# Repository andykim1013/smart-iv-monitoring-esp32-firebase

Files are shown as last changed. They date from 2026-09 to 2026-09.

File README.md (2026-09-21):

# Smart IV Monitoring System

**ESP32 · Firebase · Android · WPF 기반 디지털 수액 모니터링 시스템**

---

## 이 프로젝트는 무엇인가

- 2024년 대학교 학기설계(설계 및 프로젝트 기본II) 과목의 **팀 프로젝트**를 바탕으로 정리한 포트폴리오 저장소입니다.
- **교육 및 연구 목적의 프로토타입**이며, 실제 임상 현장에서 검증된 의료기기가 **아닙니다.**
- **실제 환자 모니터링이나 의료적 판단 목적으로 사용해서는 안 됩니다.**
- 이 저장소의 코드 중 일부는 2024년 당시 실제 소스이고, 일부는 2026년에 원본이 유실된 부분을 문서 근거로 재구성/재구현한 것입니다. 아래 "구현 상태" 표에서 정확히 구분하고 있으니 반드시 확인하십시오.

## 프로젝트 목적

당시 최종보고서를 근거로, 이 프로젝트는 다음을 목표로 했습니다.
- 로드셀(무게 센서)로 수액 팩의 무게 변화를 측정
- 적외선 센서로 수액 챔버 내 물방울 낙하를 감지
- 위 두 값으로 투여 속도와 잔여 시간을 추정
- Firebase Realtime Database로 측정값을 실시간 전송
- Android 앱과 WPF 데스크톱 프로그램으로 간호사가 원격에서 여러 환자의 수액 상태를 한눈에 모니터링

실제 구현을 넘어서는 효과(예: 임상적 안전성 향상, 의료사고 예방 등)를 이 저장소는 주장하지 않습니다. 그런 표현은 당시 보고서의 "기대효과" 서술일 뿐, 실측/임상시험으로 검증된 사실이 아닙니다.

## 시스템 구조

```
HX711 Load Cell ─┐
TCRT5000 (물방울 감지) ─┼→ ESP32 ──(WiFi)──→ Firebase Realtime Database
LCD (16x2 I2C) ───┘                                   │
                                                       ├──(읽기)──→ Android App
                                                       └──(읽기)──→ WPF Desktop App
```

- ESP32만 Firebase에 **값을 씁니다**(무게/시간/속도 측정 결과).
- Android, WPF는 모두 Firebase 값을 **읽기만** 합니다.
- 자세한 경로(path)와 근거는 [docs/firebase-setup.md](docs/firebase-setup.md) 참조.

## 구현 상태 (반드시 확인)

| 구성요소 | 현재 Repository 상태 | 출처 | 검증 |
|---|---|---|---|
| **ESP32 Firmware** | [실제 2024 원본] 그대로 보존 | `4조_디지털 수액 모니터링 시스템 개발/` 폴더의 `.ino` 원본 | 하드웨어 compile/run은 별도 미검증(소스 보존만 확인) |
| **Android — recovered-source** | [문서 원문 복원] 2024년 문서(최종보고서)에 실제 텍스트로 남아있던 코드를 그대로 옮김 | 최종보고서 ver1.5.0 부록 | 원문과 문자 단위 대조 완료 |
| **Android — reconstructed-app** | [신규 재구성] 2026년 공개 아카이브 정리 과정에서 Gradle/Manifest/리소스를 새로 작성 | recovered-source + 문서의 화면 설명 | `assembleDebug` **BUILD SUCCESSFUL**(컴파일/빌드만 검증, Firebase 런타임 연결은 별도 미검증) |
| **WPF** | [신규 재구현] 당시 전체 소스는 유실, 확인된 클래스/메서드/화면 명세만 근거로 새로 작성 | `desktop-app/README.md`의 기능 명세 | 정적 구조 검증만 완료, **실제 build 미검증**(.NET SDK 없음) |
| **CAD (.3dm/.stl)** | [실제 2024 원본] 파일명만 일반화, 내용은 SHA256 해시로 원본과 동일 확인 | 원본 폴더의 3D 케이스 설계 파일 | 해시 동일성 확인, `.3dm` 내부 문서 속성은 수동 확인 권장(아래 "알려진 한계" 참조) |

포트폴리오를 보시는 분이 **신규 재구현 코드를 2024년 원본으로 오해하지 않도록**, 이 표의 분류를 항상 기준으로 삼아주십시오.

## 실제 구현된 기능

- HX711 로드셀 기반 무게 측정
- TCRT5000 적외선 센서 기반 물방울 낙하 감지
- LCD(16x2, I2C) 출력
- NTP 서버를 이용한 시간 동기화
- 물방울 수/무게 변화 기반 투여 속도·잔여 시간·예상 종료시간 계산
- Firebase Realtime Database로 측정값 전송
- Android 앱의 층별 화면 이동 및 실시간 시작/종료 시간 표시(Firebase 리스너)
- WPF DataGrid 기반 환자 목록 모니터링(호실/이름/시작시간/종료시간/예상종료시간/진행도), 5초 주기 갱신, 환자정보 입력창

## 미구현 / 계획 (문서에만 존재)

다음은 팀 내부 메모(수정 계획)에 아이디어로만 있었고, 코드/회로 근거가 없어 이 저장소에 구현되어 있지 않습니다.
- 팔을 높게 들었을 때의 방지 알람 시스템
- 혈액 역류 방지 시스템

## 개발 과정 (초기 설계 → 최종 구현)

```
초기: Arduino UNO + Bluetooth + App Inventor(블록코딩)
   ↓
중간: ESP8266 + MySQL(구상)
   ↓
중간: ESP8266 + Firebase  ("아두이노에서 MySQL 직접 진입 불가" 판단에 따른 교체)
   ↓
최종: ESP32 + WiFi + Firebase Realtime Database + Android Studio + WPF
```

초기/중간 단계의 구성 요소(Arduino UNO, ESP8266, Bluetooth, MySQL, App Inventor)는 **모두 폐기된 설계이며 이 저장소의 최종 기술 스택에 포함되어 있지 않습니다.** 자세한 내용은 [docs/development-history.md](docs/development-history.md) 참조.

## Repository 구조

```
smart-iv-monitoring-esp32-firebase/
├── firmware/esp32_iv_monitor/          # [실제 원본] ESP32 펌웨어
├── mobile-app/
│   ├── recovered-source/               # [문서 원문 복원] Java 2개 클래스
│   └── reconstructed-app/              # [신규 재구성] 전체 Gradle 프로젝트 (빌드 성공)
├── desktop-app/
│   ├── README.md                       # WPF 기능 명세(2024년 문서 근거)
│   └── reimplemented-wpf/              # [신규 재구현] WPF 프로젝트 (build 미검증)
├── hardware/case-design/               # [실제 원본] 3D 케이스 설계(.3dm/.stl)
├── firebase/sample-data.json           # [신규 공개용 예시 데이터] synthetic
└── docs/                                # 복원/재구성 근거 문서 일체
```

## Android

- `mobile-app/recovered-source/`: **2024년 문서에서 복원**한 `MainActivity.java`, `MainActivity01.java`. 최종보고서에 package~닫는 중괄호까지 완결된 형태로 실려 있던 코드를 그대로 옮겼습니다(변수명/스타일 미수정, 원문의 버그·중복 import도 그대로 보존).
- `mobile-app/reconstructed-app/`: **2026년 공개 아카이브 정리 과정에서 재구성**한 Gradle 프로젝트 전체(Manifest, 리소스 XML, 빌드 설정)입니다. 당시 원본이 아닙니다.
- `gradle assembleDebug`가 **BUILD SUCCESSFUL**로 완료되어 `app-debug.apk`가 정상 산출되는 것을 확인했습니다. 이는 **소스/빌드 설정이 구조적으로 유효하다는 것**을 의미할 뿐이며, **Firebase 실시간 연결이 성공했다는 뜻이 아닙니다**(초기화 코드 관련 한계는 [docs/firebase-setup.md](docs/firebase-setup.md) 참조).

## WPF

- **2024년 당시 실제 WPF 전체 소스는 현재 자료에 남아있지 않습니다**(코드 본문은 스크린샷으로만 존재).
- `desktop-app/reimplemented-wpf/`는 최종보고서에서 확인된 클래스명(`MainWindow`, `Window2`), 메서드명, DataGrid 컬럼, Firebase 경로, 화면 흐름만 근거로 **공개용 포트폴리오 목적의 신규 재구현**입니다.
- Target Framework는 **net7.0-windows**를 사용했으며, 이는 2026년 공개용 재구현을 위해 선택한 값입니다. **2024년 당시 원본 WPF 프로젝트의 Target Framework는 문서에 근거가 없어 확인되지 않았습니다.**
- 이 PC에 .NET SDK가 없어 **실제 build는 미검증**입니다(XAML/구문 정적검증만 완료).
- Firebase 연동에 사용한 **FireSharp 패키지의 최신 .NET(net7.0-windows)과의 호환성도 미검증** 상태입니다.

## Firebase

- 이 저장소에는 **2024년 당시 실제 Firebase 자격증명(프로젝트 ID, API Key, 이메일/비밀번호, DB Secret)이 전혀 포함되어 있지 않습니다.**
- 이 저장소를 재현하려면 **본인의 Firebase 프로젝트(Realtime Database)를 별도로 준비**해야 합니다.
- 확인된 RTDB 경로는 `/802/StartWeight`, `/802/StartTime`, `/802/EndTime`, `/802/speed` 4개뿐입니다.
- ESP32/Android/WPF 각각의 설정 방법, 초기화 관련 한계, sample data는 [docs/firebase-setup.md](docs/firebase-setup.md)에 상세히 정리했습니다.

## Hardware / CAD

- 보드: ESP32 (초기에는 Arduino UNO → ESP8266을 거쳐 최종 교체)
- 센서: HX711 + 5kg 로드셀, TCRT5000 적외선 반사 센서(2개 구성)
- 출력: 16x2 I2C LCD(PCF8574)
- `hardware/case-design/iv_monitor_case.3dm`, `iv_monitor_case.stl`: 실제 3D 프린팅 출력에 사용된 설계 원본이며, 파일명만 공개용으로 일반화했습니다(내용은 SHA256 해시로 원본과 동일함을 확인).
- `.3dm` 파일 내부의 Rhino "문서 속성"(작성자 등 메타데이터)은 전용 도구 없이 완전히 검증하지 못했습니다 — **공개 전 Rhino에서 직접 열어 수동으로 확인하는 것을 권장합니다(manual review recommended).**

## Build / 검증 상태

| 컴포넌트 | 상태 |
|---|---|
| ESP32 Firmware | 원본 소스 보존. 실제 하드웨어 컴파일/실행은 이번 문서화 단계에서 별도로 검증하지 않았습니다. |
| Android reconstructed-app | `assembleDebug` 성공. Firebase 런타임 연결은 별도 미검증. |
| WPF reimplementation | 정적 구조(XAML well-formed, C# 구문) 검증 완료. .NET SDK 부재로 실제 build 미검증. |

## 보안 / 개인정보

- 실제 WiFi 자격증명 없음 (원본부터 자리표시자만 존재)
- 실제 Firebase 자격증명 없음
- 실제 환자 데이터 없음, 실제 의료정보 없음
- 팀원 개인정보(실명, 학번, 전화번호 등) 제거됨
- `firebase/sample-data.json`은 **신규 공개용 합성 예시 데이터**이며 실제 데이터가 아닙니다.

## 알려진 한계

- Android 코드 중 리소스(XML)·Manifest·Gradle 설정은 문서 기반으로 재구성한 것이며 당시 원본이 아닙니다.
- WPF는 전체가 기능 명세 기반의 신규 재구현입니다.
- WPF의 실제 build는 미검증입니다.
- FireSharp 패키지의 최신 .NET과의 호환성이 미검증입니다.
- 실제 Firebase 런타임 연결은 Android/WPF 모두 검증되지 않았습니다(Android는 초기화 코드 자체가 원본에 없었음).
- 실제 임상 검증이나 의료기기 인증을 받은 적이 없습니다.
- `.3dm` 파일 내부 메타데이터(작성자 등)는 일부 수동 확인이 필요할 수 있습니다.

## 원본 자료를 공개하지 않은 이유

원본 폴더에는 HWP/HWPX 최종보고서, PPTX 발표자료, 수업 평가표, 회의록 등이 있었지만 이 저장소에는 포함하지 않았습니다. 이유는 다음과 같습니다.
- 팀원 개인정보(실명, 학번, 연락처)가 포함되어 있음
- 일부 자료(평가표)에는 우리 팀 외 다른 학생들의 개인정보도 포함되어 있음
- 여러 버전이 중복되어 있어 공개 저장소에 그대로 둘 필요가 없음
- 수업 제출용 문서로, 공개 배포를 전제로 작성되지 않음

또한 원본 문서 중 일부에는 3D 모델링 소프트웨어의 비정상적인 설치 방법에 관한 설명이 포함되어 있었는데, 이 내용은 공개본에서 완전히 제외했습니다(구체적인 방법은 이 저장소 어디에도 기재하지 않았습니다).

## 관련 문서

- [docs/source-map.md](docs/source-map.md) — 모든 공개 파일의 출처와 근거 수준
- [docs/reconstruction-status.md](docs/reconstruction-status.md) — 컴포넌트별 복원/재구성 상태
- [docs/reconstruction-changes.md](docs/reconstruction-changes.md) — 3단계에서 이루어진 모든 변경의 상세 기록
- [docs/missing-source.md](docs/missing-source.md) — 여전히 원본이 없는 파일 목록과 근거
- [docs/development-history.md](docs/development-history.md) — 아키텍처 변천사(폐기 설계 포함)
- [docs/firebase-setup.md](docs/firebase-setup.md) — Firebase 연동 구조와 설정 방법

## 라이선스

이 저장소는 팀 프로젝트 결과물과 신규 재구성/재구현 코드가 혼재되어 있어, 라이선스는 아직 지정되지 않았습니다.

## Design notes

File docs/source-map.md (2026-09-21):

# Source Map

이 문서는 `smart-iv-monitoring-esp32-firebase/` 안의 각 공개용 파일이 원본 자료의 어디에서, 어떤 근거 수준으로 왔는지 추적합니다.

## Source of Truth 우선순위 (고정)
```
1순위: 실제 원본 소스파일 (.ino 등)
2순위: 최종보고서 ver1.5.0
3순위: 해당 기능 담당자의 개인보고서
4순위: 최종발표 V1.0.0
5순위: 구버전 보고서/발표자료
```
※ 상위 우선순위 자료가 있으면 그것을 그대로 사용하고, 여러 자료의 내용이 서로 다를 경우 "최신이니까"라는 이유만으로 임의로 합치지 않고 차이를 그대로 기록합니다.

## 파일별 매핑

| 공개용 파일 | 원본 출처 | 근거 수준 | 상태 | 비고 |
|---|---|---|---|---|
| `firmware/esp32_iv_monitor/esp32_iv_monitor.ino` | 원본 폴더 `4조_디지털 수액 모니터링 시스템 개발/` 내 하드웨어 담당 팀원의 `.ino` 파일 (1순위, 원본 파일명에 학번+실명 포함되어 이 문서에서는 생략) | 원본 파일 직접 복사 | **[실제 원본]** | SHA256 해시 일치, 파일명만 변경, 내용 100% 동일(검증 완료, 아래 참조) |
| `mobile-app/recovered-source/com/example/a02/MainActivity.java` | 최종보고서 ver1.5.0 부록#5 "어플리케이션 코드"(2순위), 본문 3-1 App 섹션과 문자 단위 동일, 원본 폴더 루트의 사용자메뉴얼 hwp(팀장 작성, 파일명에 학번+실명 포함되어 생략)에도 동일 텍스트 존재 | 문서 원문 텍스트 전체 발췌(package~닫는 중괄호까지 완결) | **[문서 원문 복원]** | 원문 그대로, 변수명/스타일 미수정. import 중복(`android.os.Bundle`, `androidx.appcompat.app.AppCompatActivity` 각 2회) 등 원문의 오탈자성 특징도 그대로 보존 |
| `mobile-app/recovered-source/com/example/a02/MainActivity01.java` | 최종보고서 ver1.5.0 부록#5(2순위), 본문 3-1 App 섹션과 문자 단위 동일(줄바꿈 차이만) | 문서 원문 텍스트 전체 발췌(package~닫는 중괄호까지 완결) | **[문서 원문 복원]** | 미사용 필드 `textView03`, `onCancelled`에서 `Starttime` 콜백인데 `textViewend1`을 갱신하는 원본 버그 등 그대로 보존 (임의 수정 없음) |
| `desktop-app/README.md` | 최종보고서 ver1.5.0 "3-2 프로그램"(2순위), WPF 담당 팀원 개인보고서(3순위) | 클래스/메서드명·역할 설명 텍스트만(코드 본문은 스크린샷이라 텍스트 없음) | **[설명만 존재]** | 실제 `.xaml`/`.cs` 코드는 어디에도 텍스트로 존재하지 않음. FireSharp 패키지명은 3순위 자료에서 텍스트로 직접 확인됨 |
| App Inventor 관련 자산 | 역설계 단계 회의록·PPT | 사용 사실만 텍스트로 확인, `.aia` 파일 없음 | **[폐기 설계]** | 최종 구현은 Android Studio로 전환되어 App Inventor 산출물은 최종 구현에 포함하지 않음 |
| Arduino UNO / ESP8266 / Bluetooth / MySQL 직접연동 | 1~3차 회의록 | 텍스트로 명시적 확인 | **[폐기 설계]** | 최종 아키텍처(ESP32+WiFi+Firebase)로 대체되어 반영하지 않음 |
| 팔 높게 들기 방지 알람 / 혈액 역류 방지 시스템 | `수정목록.txt` | 아이디어 수준 텍스트만 | **[미구현]** | 코드/회로 근거 전혀 없음 |

### 3단계 신규 추가분

| 공개용 파일 | 원본 출처 | 근거 수준 | 상태 | 비고 |
|---|---|---|---|---|
| `mobile-app/reconstructed-app/app/src/main/java/com/example/a02/MainActivity.java`, `MainActivity01.java` | recovered-source 동일 파일 | recovered-source 복사 + 컴파일 에러 1건 최소 수정(EdgeToEdge import 제거) | **[문서 원문 복원 + 최소 빌드 수정]** | 수정 내역은 `docs/reconstruction-changes.md` "Android 원문 수정 내역" 참조. recovered-source 자체는 무수정 |
| `mobile-app/reconstructed-app/app/src/main/res/layout/activity_main.xml`, `activity_main01.xml` | 최종보고서 ver1.5.0 "코드 설명" 텍스트(색상 hex, 텍스트 문구) + recovered Java의 View ID | 텍스트 근거 기반 근사 재현 (ConstraintLayout/CardView → 표준 위젯으로 대체, 사유는 reconstruction-changes.md) | **[신규 재구성]** | 원본 XML 아님. `card_background_main`(#ECF1E6), `room_background`(#EAF1E1)만 문서 원문 hex, 나머지 색상은 근사치 |
| `mobile-app/reconstructed-app/app/src/main/AndroidManifest.xml`, `*.gradle`, `colors.xml`, `strings.xml`, `themes.xml`, `border_shape.xml`, `card_background.xml` | 근거 없음(Manifest/Gradle), 또는 텍스트 근거 기반 근사(리소스) | 신규 작성 | **[신규 재구성]** | `docs/reconstruction-changes.md` 참조 |
| `desktop-app/reimplemented-wpf/**` (전체: .sln, .csproj, App/MainWindow/Window2 .xaml/.cs, PatientRow.cs, FirebaseSettings.example.cs) | `desktop-app/README.md`의 확인된 클래스/메서드/Firebase 경로/DataGrid 컬럼 명세 | 명세 기반 신규 구현(코드 본문 원문 없음) | **[신규 재구현]** | 당시 원본 WPF 소스가 아님. FireSharp 호환성 미검증(SDK 없음), 자세한 내용은 `docs/reconstruction-changes.md` |
| `hardware/case-design/iv_monitor_case.3dm`, `iv_monitor_case.stl` | 원본 `케이스 외형 출력 디자인.3dm`(2024-11-18) / `.stl`(2024-11-19) | 원본 파일 직접 복사 | **[실제 원본]** | SHA256 해시 일치, 파일명만 일반화. 선정 근거는 `docs/reconstruction-changes.md` "CAD 최종본 조사" 참조 |
| `케이스 외형 출력 디자인1.3dm` 등 나머지 CAD 후보 | 원본 폴더 | STL과 미대응 | **[판단 불가]**(공개용 미포함) | 최신 수정일이지만 대응 STL 없음 — 다음 단계에서 사용자 확인 후 포함 여부 결정 |

## ESP32 펌웨어 원본 동일성 검증 상세
```
원본: 2학년 2학기 설계/4조_디지털 수액 모니터링 시스템 개발/ 폴더 내 하드웨어 담당 팀원의 .ino 파일 (파일명에 학번+실명 포함되어 이 문서에서는 생략)
사본: firmware/esp32_iv_monitor/esp32_iv_monitor.ino

SHA256(원본) = 61faf2f7c8b4062545676607af73021d955608b7ad703fb4b8de788f67593ac7
SHA256(사본) = 61faf2f7c8b4062545676607af73021d955608b7ad703fb4b8de788f67593ac7
diff 결과   = 차이 없음 (0 lines)
파일 크기    = 13,711 bytes (동일)

결론: 파일명만 공개용으로 일반화되었을 뿐, 내용은 100% 동일한 원본입니다.
```

## 참고: 최종보고서 부록4(펌웨어 코드)와 .ino 원본의 관계
최종보고서 ver1.5.0 부록#4 "소스 코드"에 실린 ESP32 코드는 `.ino` 원본과 실질적으로 동일한 내용(변수/로직/주석 일치, 코드 종료부 문자열까지 정확히 일치 확인)입니다. 다만 이번 2단계에서는 **1순위 자료인 `.ino` 파일 자체**를 그대로 사용했으므로, 부록4 텍스트는 교차검증 용도로만 참고했습니다.

## Android 코드 본문·부록 간 동일성
최종보고서 본문(3-1 App 섹션)과 부록#5(어플리케이션 코드)에 실린 `MainActivity`/`MainActivity01` 코드는 줄바꿈 유무를 제외하면 **완전히 동일**합니다(문자 단위 diff 결과 실질 차이 없음). 서로 다른 버전이 아니라 같은 코드가 본문과 부록에 중복 수록된 것으로 판단했습니다.

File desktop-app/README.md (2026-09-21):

# Desktop App (WPF / C#) — 사양 문서 (소스 미확보)

> 이 문서는 **소스 코드가 아니라 복원 근거 문서**입니다.
> 원본 자료(최종보고서 ver1.5.0, WPF 담당자 개인보고서, 최종발표 V1.0.0)를 전수 조사한 결과,
> 이 프로그램의 **실제 텍스트 형태 전체 소스코드(.xaml, .xaml.cs, .csproj, .sln)는 현재 자료에 존재하지 않습니다.**
> 존재하는 것은 클래스/메서드 이름, 역할 설명, 화면 스크린샷(이미지)뿐이며, 이번 2단계에서는 이 정보만 문서화하고
> `.xaml` / `.xaml.cs` / `.csproj` / `.sln` 파일은 **생성하지 않았습니다.**

## 근거 자료
| 자료 | 근거 수준 |
|---|---|
| 최종보고서 ver1.5.0 "3-2 프로그램" 섹션 | 클래스/메서드 이름 + 역할 설명 텍스트, 코드 본문은 스크린샷(이미지) |
| WPF 담당 팀원 개인보고서 (원본 폴더 내 hwpx 파일 — 파일명에 학번+실명 포함되어 이 문서에서는 생략) | FireSharp 패키지 설치 절차 설명 + import 문 일부(`using FireSharp;` 등 패키지명만) 텍스트, 코드 본문은 스크린샷 |
| 최종발표 V1.0.0 PPT | 코드/클래스 관련 텍스트 없음 (해당 없음) |

## 확인된 기술 스택
- **UI 프레임워크**: WPF (Windows Presentation Foundation)
- **언어**: C#
- **Firebase 연동 패키지**: **FireSharp** (NuGet 패키지, WPF에서 Firebase Realtime Database 연동용으로 명시적으로 언급됨)
- **연동 대상**: Firebase Realtime Database (ESP32 펌웨어와 동일한 DB)

## 확인된 화면(클래스) 구성
### MainWindow
- 역할: 간호사 데스크가 여러 환자의 수액 상태를 한 화면에서 확인하는 메인 화면
- 구성 요소: `DataGrid` — 컬럼: **호실, 이름, 시작시간, 종료시간, 예상종료시간, 진행도**
- 동작: 프로그램 시작 시 호실을 제외한 셀은 공백으로 표시, 이름 열에 `Window2`를 여는 버튼 존재
- 실시간 업데이트: 타이머로 **5초 주기** 갱신, Firebase 값 변경 시에도 갱신

### Window2
- 역할: 환자 정보 입력 창 (이름, 투여 시간, 투여 용량, 수액 종류 입력)
- 동작: 입력 후 [확인] 버튼 클릭 시 창이 닫히고 `MainWindow`의 `DataGrid` 해당 행에 정보 반영
- 투여 시간은 분 단위 입력을 `TimeSpan`("00:00:00" 형식)으로 변환해 저장

## 확인된 메서드 이름과 역할 (본문 텍스트 근거, 구현 코드 본문은 없음)
| 메서드 | 소속(추정) | 역할 설명(원문 근거) |
|---|---|---|
| `UpdateInfo` | MainWindow | `Window2` 종료 시 실행, 입력값을 `DataGrid`에 반영 |
| `Info` | MainWindow | `MainWindow` 실행 시 `DataGrid` 행 생성 |
| `Setting` | MainWindow | Firebase에서 가져온 데이터를 가공 |
| `OnTimeEvent` | MainWindow | 행마다 데이터 존재 여부 확인 후 현재 값 계산·갱신 |
| `UpdateInfoForItem` | MainWindow | Firebase에서 가져온 데이터 변환 |
| `LoadData` | MainWindow | 프로그램 실행 시 `DataGrid` 생성(호실 제외 공백 처리) |
| `Read_Value` | MainWindow | Firebase에서 `speed`, `EndTime` 일부 데이터 조회 (`Window2` 종료 시 동작) |
| `BtnName_Click` | MainWindow | `[입력]` 버튼 클릭 시 `Window2` 실행 및 종료 후 값 저장 |
| `SetNowEnd` | MainWindow | 예상종료시간·진행도 계산에 필요한 시작무게/시작시간 저장, `DataGrid` 갱신 |
| `btn1_Click` | Window2 | 입력값 저장, `MainWindow`에서 사용 가능한 형식으로 변환 |

## 확인 가능한 Firebase 데이터 구조 (ESP32 펌웨어와 공유)
```
/802/StartTime
/802/EndTime
/802/speed
/802/StartWeight
```
(802는 예시 병실 호실 번호로, 문서 내 시연 예시입니다.)

## 환자정보 입력 흐름 (문서 근거)
```
프로그램 실행 → MainWindow 로드 → DataGrid에 호실만 표시(나머지 공백)
   ↓ [이름 열의 입력 버튼 클릭] (BtnName_Click)
Window2 표시 → 이름 / 투여시간(분→TimeSpan 변환) / 투여용량 / 수액종류 입력
   ↓ [확인] 버튼 (btn1_Click)
입력값 저장 → Window2 종료 → UpdateInfo 실행 → DataGrid 해당 행 갱신
   ↓ (백그라운드, 5초 주기)
Firebase에서 speed/EndTime 등 재조회(Read_Value) → 진행도·예상종료시간 재계산 → DataGrid 갱신
```

## 명시적으로 하지 않은 것 (2단계 기준)
- `.xaml` / `.xaml.cs` / `.csproj` / `.sln` 신규 작성 — 2단계에서는 하지 않음
- 위 메서드 이름을 기반으로 한 코드 본문 추측/작성 — 2단계에서는 하지 않음
- FireSharp 연동 코드, DataGrid 바인딩 코드 등 실제 구현부 재현 — 2단계에서는 하지 않음

## 3단계 갱신: 재구현 완료
위 명세를 근거로 3단계에서 [reimplemented-wpf/](reimplemented-wpf/)에 **[신규 재구현]** 코드를 작성했습니다(당시 원본이 아님). `.NET SDK`가 이 PC에 없어 실제 build는 검증하지 못했고(정적검증만 완료), FireSharp의 net7.0-windows 호환성도 미검증입니다. 상세 내용은 [../docs/reconstruction-changes.md](../docs/reconstruction-changes.md)와 [../docs/reconstruction-status.md](../docs/reconstruction-status.md)를 참조하십시오.

## 결론
WPF 데스크톱 프로그램은 **당시 실제 소스가 유실**된 상태였고, 이 문서는 재구현의 근거가 된 **기능 명세서**입니다. 실제 재구현 코드는 `reimplemented-wpf/`에 있습니다.

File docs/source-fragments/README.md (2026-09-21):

# Source Fragments

이 폴더는 "완전한 클래스가 아니어서 `.java`로 만들지 않은 부분 소스"를 기록하기 위한 폴더입니다.

## 현재 상태: 해당 없음 (Android)
최종보고서 ver1.5.0 + Android 담당 팀원 개인보고서를 전수 조사한 결과, 텍스트로 발견된 Android 코드는 **`MainActivity`, `MainActivity01` 2개뿐이며 둘 다 package~닫는 중괄호까지 완전한 클래스**였습니다. 그 외 활동(층별 병실 화면 등)에 대한 코드 텍스트는 전혀 발견되지 않았고(설명/스크린샷만 존재), "일부만 있는 코드 조각" 자체가 없어 이 폴더에는 현재 아무 파일도 없습니다. 완전한 두 클래스는 `mobile-app/recovered-source/`에 있습니다.

## WPF 관련 부분 증거
WPF(MainWindow/Window2)는 클래스명·메서드명·역할 설명 등 "부분 증거"가 있지만, 사용자 지시에 따라 이 폴더가 아니라 `../../desktop-app/README.md`에 기능 명세 형태로 정리했습니다(코드 조각이 아니라 스펙 문서이므로).

## 향후
다음 단계에서 하드웨어 담당 팀원 개인보고서 등을 더 정밀하게 재조사할 경우, 진짜 "일부만 있는 코드 조각"이 발견되면 이 폴더에 근거와 함께 `[부분 소스]`로 추가할 수 있습니다.

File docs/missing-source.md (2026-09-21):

# Missing Source

다음 단계(재구성)에서 다루어야 할, 현재 원본 텍스트가 없는 파일 목록입니다. 이번 2단계에서는 이 파일들을 **생성하지 않았습니다.**

> **3단계 갱신 안내**: 아래 목록 중 대부분은 3단계에서 `mobile-app/reconstructed-app/`, `desktop-app/reimplemented-wpf/`에 **[신규 재구성]/[신규 재구현]**으로 실제 작성되었습니다. 이 문서는 "당시 원본이 없었다"는 2단계 시점의 분석 기록을 그대로 보존하기 위해 수정하지 않았고, 각 항목이 어떤 파일로 재구성되었는지는 `docs/source-map.md`의 "3단계 신규 추가분" 표와 `docs/reconstruction-changes.md`를 참조하십시오. **유일하게 계속 미해결로 남은 항목은 "추가 Activity (2층~6층 병실 화면)"입니다** — 근거가 없어 3단계에서도 생성하지 않았습니다.

---

### AndroidManifest.xml
- 원본 존재 여부: 없음
- 근거: 최종보고서·개인보고서 어디에도 텍스트/설명 없음(존재 자체가 언급되지 않음)
- 복원 가능성: 불가(근거 없음)
- 신규 작성 필요 여부: 필요(재구성 단계에서 처음부터 작성해야 함, 이번 단계 범위 아님)

### Gradle 파일 (build.gradle, settings.gradle, gradle.properties, gradle wrapper)
- 원본 존재 여부: 없음
- 근거: 없음
- 복원 가능성: 불가
- 신규 작성 필요 여부: 필요(재구성 단계, 이번 단계 범위 아님)

### activity_main.xml
- 원본 존재 여부: 텍스트 원본 없음
- 근거: 최종보고서에 파일명("메인화면 레이아웃(activity_main.xml)")과 화면 스크린샷만 존재, `R.id.button2` 등 일부 리소스 ID는 `MainActivity.java` 코드에서 간접 확인 가능
- 화면/기능 설명: 층별 버튼 6개(1~6층), ConstraintLayout, CardView(층별 버튼 배경), TextView("건양대학병원", "4조"), ImageView(로고)
- 복원에 사용할 수 있는 자료: 최종보고서 스크린샷(이미지, 텍스트 아님), `MainActivity.java`가 참조하는 `R.id.button2`
- 신규 작성 필요 여부: 필요(레이아웃 XML 자체 재작성 필요, 이번 단계 범위 아님)

### activity_main01.xml
- 원본 존재 여부: 텍스트 원본 없음
- 근거: 최종보고서에 파일명("병실화면")과 화면 스크린샷만 존재. `R.id.textViewend1`, `R.id.textViewstart1`, `R.id.button05`는 `MainActivity01.java` 코드에서 간접 확인
- 화면/기능 설명: 801~803호실 등 TextView, 시작시간/종료시간/공실 여부 표시, 침대 번호 1~14, 사각 테두리(border_shape), 상단 건양대 로고+뒤로가기 버튼
- 복원에 사용할 수 있는 자료: 최종보고서 스크린샷(이미지), 코드 내 리소스 ID 참조
- 신규 작성 필요 여부: 필요(이번 단계 범위 아님)

### color.xml
- 원본 존재 여부: 텍스트 원본 없음
- 근거: "필요한 색상을 코드로 만들어 재사용" 설명 텍스트 + `@color/green`, `@color/green2` 참조가 `MainActivity`/설명 텍스트에서 확인됨(정확한 hex 값은 스크린샷에만 존재, 읽을 수 없음)
- 복원 가능성: 색상 이름만 확인, 실제 hex 값은 [내용 확인 불가]
- 신규 작성 필요 여부: 필요

### border_shape.xml
- 원본 존재 여부: 텍스트 원본 없음
- 근거: "병실 화면 호실마다 침대의 네모난 빈 틀을 만드는 코드" 설명 텍스트만 존재, 내용은 스크린샷
- 신규 작성 필요 여부: 필요

### 추가 Activity (2층~6층 병실 화면)
- 원본 존재 여부: 없음
- 근거: 최종보고서·개인보고서 모두 "802호실" 1개 사례만 텍스트/코드로 제시. "각 층의 호실을 한눈에 확인"이라는 목표 설명은 있으나, 층별로 별도 Activity가 몇 개 존재하는지, 이름 규칙(MainActivity02~06 등)이 무엇인지는 **어디에도 근거가 없음**
- 복원 가능성: 불가 — `MainActivity01`을 층/호실별로 복제했을 가능성은 있으나 추정일 뿐이므로 [내용 확인 불가]로 처리, 임의로 파일을 만들지 않음
- 신규 작성 필요 여부: 판단 보류(다음 단계에서 결정)

### WPF project files (.csproj, .sln)
- 원본 존재 여부: 없음
- 근거: 없음
- 신규 작성 필요 여부: 필요(재구현 단계, 이번 범위 아님)

### MainWindow.xaml / MainWindow.xaml.cs
- 원본 존재 여부: 텍스트 원본 없음(클래스명/메서드명/역할 설명만 텍스트, 코드 본문은 스크린샷)
- 근거: `desktop-app/README.md` 참조
- 복원 가능성: 불가(코드 본문 텍스트 없음)
- 신규 작성 필요 여부: 필요(재구현, 이번 범위 아님)

### Window2.xaml / Window2.xaml.cs
- 원본 존재 여부: 텍스트 원본 없음(위와 동일한 사유)
- 신규 작성 필요 여부: 필요(재구현, 이번 범위 아님)

### Firebase configuration (google-services.json, firebase config 등)
- 원본 존재 여부: 없음(원본 자료 어디에도 설정 파일 자체는 존재하지 않음, API Key/URL은 전부 플레이스홀더 텍스트로만 언급됨)
- 근거: `.ino` 및 최종보고서 부록의 `#define API_KEY "파이어베이스 API 키 작성"` 등
- 복원 가능성: 불가(실제 값 자체가 원본에도 없었음 — 유실이 아니라 "애초에 비공개 처리된 상태")
- 신규 작성 필요 여부: 다음 단계에서 사용자가 직접 발급해야 함(복원 대상 아님)

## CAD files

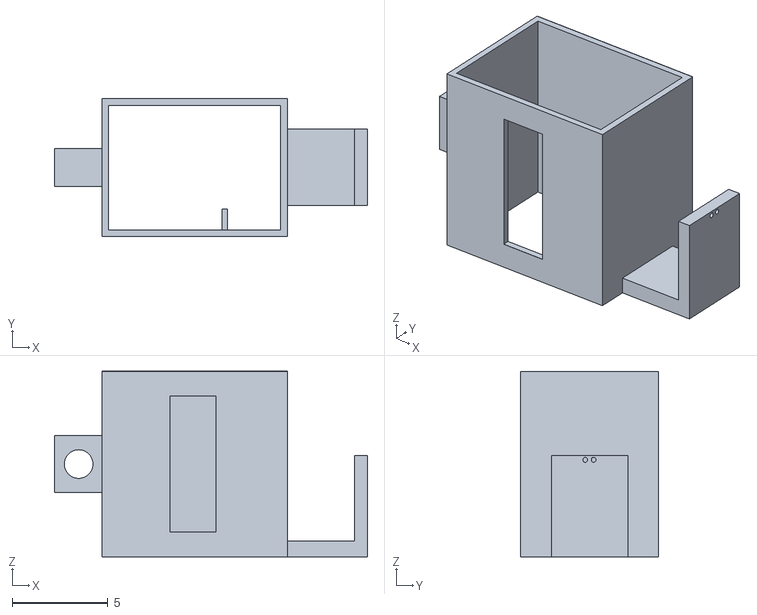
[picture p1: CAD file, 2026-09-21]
hardware/case-design/iv_monitor_case.stl
16.4 x 7.20 x 9.72

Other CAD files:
hardware/case-design/iv_monitor_case.3dm

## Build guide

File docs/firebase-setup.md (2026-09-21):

# Firebase Setup

이 문서는 이 저장소의 각 컴포넌트가 Firebase Realtime Database(RTDB)를 실제로 어떻게 사용하는지, 그리고 이 저장소를 직접 실행해보려는 사람이 무엇을 준비해야 하는지를 설명합니다. 아래 내용은 실제 코드(`firmware/`, `mobile-app/`, `desktop-app/`)를 다시 읽고 확인한 결과이며, 추측은 [확인 불가]로 표시했습니다.

## 1. Firebase Realtime Database의 역할

이 프로젝트에서 Firebase RTDB는 ESP32와 두 모니터링 클라이언트(Android, WPF) 사이의 유일한 데이터 통로입니다. 아두이노-앱-데이터베이스가 직접 연결되던 초기 구조(블루투스/MySQL, [docs/development-history.md](development-history.md) 참조)가 재설계 과정에서 이 구조로 바뀌었습니다.

```
ESP32 (HX711 + TCRT5000 + LCD)
   │  Firebase.setFloat / Firebase.setString  (쓰기)
   ▼
Firebase Realtime Database  ──────────────┐
   │  FirebaseDatabase.getInstance()...    │  IFirebaseClient.GetAsync(...)
   │  (읽기)                                │  (읽기)
   ▼                                        ▼
Android App (MainActivity01)         WPF Desktop (MainWindow)
```

ESP32만 쓰기(write)를 수행하고, Android와 WPF는 모두 읽기(read) 전용으로 동작합니다. 이는 recovered-source(Java)와 reimplemented-wpf(C#) 코드 어디에도 Firebase에 값을 **쓰는(set) 호출이 없다는 사실**로 확인했습니다.

## 2. 확인된 RTDB path / schema

세 컴포넌트(펌웨어, Android, WPF)의 실제 코드를 대조한 결과, 아래 4개 경로만 확인되었습니다. `802`는 최종보고서·코드 양쪽에서 예시로 등장하는 병실/침대 번호이며, 실제로는 임의의 호실 번호가 들어갈 수 있는 자리입니다.

| Path | 타입 | 쓰는 주체 | 읽는 주체 |
|---|---|---|---|
| `/802/StartWeight` | float | ESP32 | (읽는 코드 없음, 확인 안 됨) |
| `/802/StartTime` | string | ESP32 | Android |
| `/802/EndTime` | string | ESP32 | Android, WPF |
| `/802/speed` | float | ESP32 | WPF |

이 4개 외에 코드/문서로 확인되는 필드는 없습니다. 문서 본문에는 "환자 이름, 투여 용량, 수액 종류"도 언급되지만, 이 값들이 실제로 Firebase에 쓰였다는 코드 근거는 없어(WPF Window2 입력값은 화면에만 반영되는 것으로 확인) **schema에 포함하지 않았습니다.**

## 3. ESP32가 사용하는 설정

`firmware/esp32_iv_monitor/esp32_iv_monitor.ino`(2024년 실제 원본, 이번 4단계에서도 **수정하지 않음**)는 다음 상수를 코드에 직접 선언합니다.

```cpp
const char* ssid = "와이파이 이름 작성";
const char* password = "와이파이 비밀번호 작성";
#define API_KEY "파이어베이스 API 키 작성"
#define DATABASE_URL "파이어 베이스 URL 주소 작성"
#define USER_EMAIL "사용자 이메일"
#define USER_PASSWORD "비밀번호 작성"
```

원본부터 실제 값이 아니라 사람이 채워 넣어야 할 자리표시자였습니다. 이 저장소에서는 이 구조를 `secrets.h` 같은 별도 헤더 파일로 리팩터링하지 않았습니다 — **원본 소스를 그대로 보존하는 것이 우선**이기 때문입니다. 이 파일을 직접 사용하려면 위 6개 값을 본인의 WiFi/Firebase 정보로 직접 채워 넣으십시오(파일을 열어 편집).

## 4. Android가 사용하는 설정

`mobile-app/reconstructed-app/app/build.gradle`을 확인한 결과:
- `com.google.gms:google-services` 플러그인이 적용되어 있지 **않습니다.**
- `google-services.json`을 참조하는 코드/설정이 어디에도 없습니다.
- `recovered-source`/`reconstructed-app`의 `MainActivity.java`, `MainActivity01.java`에도 `FirebaseApp.initializeApp(...)`이나 `FirebaseOptions`를 이용한 수동 초기화 코드가 없습니다. `FirebaseDatabase.getInstance()`를 곧바로 호출할 뿐입니다.

**결론**: 현재 Gradle 구조는 `google-services.json`을 필요로 하지 않지만, 그 이유는 "설정이 필요 없어서"가 아니라 **Firebase 초기화 코드 자체가 원본 문서에 없어서**입니다. 즉 이 상태로는 앱을 실제 기기에서 실행해도 `FirebaseDatabase.getInstance()` 호출 시점에 "Default FirebaseApp이 초기화되지 않았다"는 런타임 오류가 발생할 가능성이 높습니다. 이는 **알려진 한계**이며, 이번 4단계(문서화 단계)에서는 코드를 추가로 개발하지 않았으므로 `google-services.example.json` 같은 템플릿도 만들지 않았습니다. 실제로 앱을 동작시키려면 다음 단계 중 하나가 **추가로 필요**합니다(둘 다 이번 저장소 범위 밖의 작업):
1. `com.google.gms:google-services` 플러그인 적용 + 본인의 `google-services.json` 추가, 또는
2. `Application` 클래스 등에서 `FirebaseOptions.Builder()`로 API Key/DB URL을 직접 넣어 수동 초기화하는 코드 추가

## 5. WPF가 사용하는 설정

`desktop-app/reimplemented-wpf/IvMonitorDesktop/FirebaseSettings.example.cs`에 두 필드만 존재합니다.

```csharp
public const string AuthSecret = "YOUR_FIREBASE_AUTH_SECRET";
public const string BasePath = "https://YOUR_PROJECT_ID.firebaseio.com/";
```

`MainWindow.xaml.cs`는 이 두 필드(`FirebaseSettings.AuthSecret`, `FirebaseSettings.BasePath`)만 참조하며 다른 필드는 없습니다. 실제로 사용하려면 `FirebaseSettings.example.cs`를 복사해 `FirebaseSettings.cs`(같은 폴더, 같은 네임스페이스)로 만들고 두 값을 채우십시오. `FirebaseSettings.cs`는 `.gitignore`에 등록되어 있어 실수로 커밋되지 않습니다.

## 6. Credential을 Repository에 포함하지 않는 정책

이 저장소에는 다음이 **전혀 포함되어 있지 않습니다.**
- 2024년 당시 실제 Firebase 프로젝트 ID
- 실제 Firebase API Key / DB URL
- 실제 Firebase 로그인 이메일/비밀번호 또는 Auth Secret
- 실제 WiFi SSID/비밀번호

이 저장소를 재현하려면 **사용자가 자신의 Firebase 프로젝트(Realtime Database 활성화)를 별도로 준비**해야 하며, 위 3~5절의 설정 자리에 자신의 값을 채워야 합니다.

## 7. Android build 성공 ≠ Firebase runtime 연결 검증

`mobile-app/reconstructed-app`는 `gradle assembleDebug`로 **컴파일/빌드 성공**을 확인했습니다(`docs/reconstruction-status.md` 참조). 이것은 **소스 코드 구조와 의존성 해석이 정상**임을 의미할 뿐이며, 실제 기기/에뮬레이터에서 앱을 실행해 Firebase에 실시간으로 연결되는지는 **검증하지 않았습니다**(4절에서 설명한 초기화 누락 문제도 있어 현재 상태로는 런타임 연결이 되지 않을 가능성이 높습니다).

## 8. WPF Firebase 연동은 build/runtime 모두 미검증

`desktop-app/reimplemented-wpf`는 이 PC에 .NET SDK가 설치되어 있지 않아 `dotnet build` 자체를 실행하지 못했습니다(XAML/구문 정적검증만 완료). 따라서 컴파일 성공 여부, FireSharp 패키지의 실제 호환성, Firebase 런타임 연결 모두 **미검증** 상태입니다.

## 9. Sample data

`firebase/sample-data.json`에 위 2절의 schema(경로 4개)만 사용한 **신규 공개용 예시 데이터**를 두었습니다. 실제 2024년 DB 덤프가 아니며, 실제 환자정보·의료정보를 포함하지 않습니다.

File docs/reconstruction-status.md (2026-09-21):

# Reconstruction Status

컴포넌트별 복원 상태를 기록합니다. "복원"은 근거가 명확한 것만 포함하며, 근거 없는 추측은 포함하지 않습니다.

---

## ESP32 Firmware
**상태: 실제 원본 확보 (100%)**
- `esp32_iv_monitor.ino` — 원본 파일 SHA256 해시 일치, 완전 동일 사본
- 센서 핀 설정, HX711 무게 처리, TCRT5000 물방울 카운트, LCD 출력, 시간 계산/예상 종료시간 계산, Firebase 데이터 경로, NTP, loop 주기 — **모두 원본 그대로이며 어떤 것도 리팩터링하지 않았습니다.**
- WiFi SSID/비밀번호, Firebase API Key/URL/이메일/비밀번호는 원본부터 "OOO 작성"류 플레이스홀더였고, 이번 단계에서는 `secrets.h` 구조로도 바꾸지 않았습니다(다음 공개 정리 단계에서 별도 판단).

## Android (mobile-app)
**상태(3단계 갱신): Original source partially recovered (2 classes) + reconstructed build scaffolding added — BUILD SUCCESSFUL**

- `recovered-source/`: 아래 "부분 소스 확보" 내용 그대로, **3단계에서 한 글자도 수정하지 않음**
- `reconstructed-app/`: recovered-source를 복사해 최소 수정(컴파일 에러 1건)한 뒤, Gradle/Manifest/리소스를 신규 재구성해 실제 `assembleDebug` 빌드에 **성공**(APK 산출 확인, 이후 `gradle clean`으로 빌드 산출물은 정리함)
- 상세 검증 내용은 이 문서 하단 "3단계: 실제 빌드 검증 결과" 참조

**상태(2단계): 부분 소스 확보 — 완전한 클래스 2개만 복원**
- 문서(최종보고서 ver1.5.0 본문+부록, 사용자메뉴얼)에서 다음 2개 클래스가 **package~닫는 중괄호까지 완결된 형태**로 확인되어 `.java`로 복원했습니다.
  - `MainActivity.java` — package, imports, class 선언, `onCreate`, 버튼 클릭 리스너, `Intent` 이동, 닫는 중괄호까지 전부 존재
  - `MainActivity01.java` — package, imports, class 선언, 필드(`textView03`, `textViewend1`, `textViewstart1`, `Starttime`, `Endtime`), `onCreate`, Firebase `ValueEventListener` 2개(`onDataChange`/`onCancelled`), 버튼 클릭 리스너, 닫는 중괄호까지 전부 존재
- **원문 그대로 보존한 특이사항(임의 수정하지 않음)**:
  - `MainActivity.java`: `import android.os.Bundle;`, `import androidx.appcompat.app.AppCompatActivity;`가 각각 2회 중복 선언됨(원본 그대로)
  - `MainActivity01.java`: 필드 `textView03`이 선언만 되고 본문에서 사용되지 않음(원본 그대로)
  - `MainActivity01.java`: `Starttime.addValueEventListener(...)`의 `onCancelled` 콜백 내부에서 `textViewstart1`이 아니라 `textViewend1.setText(...)`을 호출함 — **원본 문서에 실제로 이렇게 적혀 있는 버그로 보이는 부분**이며, 임의로 고치지 않고 그대로 옮겼습니다.
  - 두 클래스 모두 최종보고서 텍스트에는 코드 라인에 들여쓰기가 없는 상태로 남아 있었습니다(HWP 원본의 문단 서식 때문인지, 학생이 원래 들여쓰기 없이 작성했는지는 확인 불가). 이번 복원에서는 **원문 그대로 들여쓰기를 추가하지 않고** 발췌된 형태를 유지했습니다.
- **복원하지 않은 것**: 그 외 언급되는 XML 리소스, Manifest, Gradle 설정 — 텍스트 원문이 없어 `docs/missing-source.md`에 별도 기록

## WPF (desktop-app)
**상태(3단계 갱신): Original source unavailable — portfolio reimplementation added (build UNVERIFIED, no .NET SDK)**

- `desktop-app/README.md`(기능 명세)는 2단계 그대로 유지
- `reimplemented-wpf/`: README의 명세(클래스명 10개 메서드, DataGrid 6컬럼, Firebase 경로, 5초 주기, FireSharp)를 근거로 **전체 신규 재구현**(MainWindow, Window2, PatientRow, FirebaseSettings.example)
- **build는 검증하지 못했습니다**: 이 PC에 .NET SDK가 설치되어 있지 않아(`dotnet --list-sdks` 결과 없음, 런타임만 존재) `dotnet restore`/`build` 자체를 실행할 수 없었습니다. XAML well-formed 여부와 C# 중괄호/괄호 균형 등 **정적검증만 완료**했습니다.
- FireSharp(2.0.4)은 .NET Framework 4.5 세대 라이브러리로 알려져 있어 net7.0-windows와의 실제 호환성이 미검증 상태입니다(다른 라이브러리로 임의 교체하지 않음). 상세는 `docs/reconstruction-changes.md` 참조.

## CAD
**상태(3단계 갱신): 실제 원본 보존 + 공개용 최종본 1쌍 복사 완료(해시 검증됨)**
- 최종본으로 선정: `케이스 외형 출력 디자인.3dm`(2024-11-18, STL과 페어링됨) + `케이스 외형 출력 디자인.stl`(2024-11-19, 폴더 내 유일한 STL)
- `hardware/case-design/iv_monitor_case.3dm`, `iv_monitor_case.stl`로 파일명만 일반화해 복사, SHA256 해시로 원본과 완전 동일함을 확인
- `.3dmbak`(3개)와 "케이스 외형 출력 디자인1.3dm"(날짜상 더 최신이나 대응 STL 없음)은 복사하지 않음 — 근거는 `docs/reconstruction-changes.md` "CAD 최종본 조사" 참조
- 3dm 내부 OpenNURBS "문서 속성"(작성자 등)은 전용 도구 없이 완전히 확인 불가 — [확인 불가]로 명시, 텍스트 패턴 스캔으로는 PII 미검출

---

## 3단계: 실제 빌드 검증 결과

### Android
```
환경: Gradle 8.9(로컬 캐시), AGP 8.6.0, JDK 21, Android SDK platform 34/35 (모두 이 PC에 기존 설치되어 있던 것 사용, 신규 설치 없음)
명령: gradle assembleDebug
결과: BUILD SUCCESSFUL — app-debug.apk 산출 확인 후 gradle clean으로 산출물 정리
```
과정에서 발견/조치한 문제 2건(모두 `docs/reconstruction-changes.md`에 상세 기록):
1. `firebase-database`가 끌어오는 구버전 `kotlin-stdlib-jdk7/jdk8`이 최신 `kotlin-stdlib`과 클래스 중복 → 버전을 올리지 않고 구버전 transitive 모듈만 `exclude`
2. `androidx.constraintlayout`/`androidx.cardview`의 커스텀 XML 속성이 이 환경의 AAPT2 리소스 링크 단계에서 인식되지 않음(원인 미특정, 한글 경로·캐시 오염은 배제됨) → 표준 프레임워크 위젯(`LinearLayout`+shape drawable)으로 대체

### WPF
```
환경: .NET 7 런타임만 설치(SDK 없음)
결과: 정적검증(XAML well-formed, C# 중괄호/괄호 균형)만 완료 / 실제 build 미검증
```

## App Inventor
**상태: 최종 구현에서 제외**
- 역설계 단계(2024.09)에서 사용된 사실은 회의록/PPT로 확인되나, `.aia` 원본 파일이 자료에 없고 최종 구현은 Android Studio로 전면 교체됨
- 새 App Inventor 프로젝트를 생성하지 않았으며, 전환 과정만 `development-history.md`에 서술

## 폐기 아키텍처 (Arduino UNO / ESP8266 / Bluetooth / MySQL 직접연동)
**상태: 최종 구현에서 완전히 제외**
- 회의록(2·3차)에 폐기 결정이 명시적으로 기록되어 있어, 최종 구현물에 포함하지 않고 `development-history.md`에 "폐기 설계"로만 기록

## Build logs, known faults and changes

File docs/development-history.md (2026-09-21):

# Development History

회의록·발표자료에서 확인된 기술적 의사결정 변화만 정리했습니다(개인정보 제외). 최종 구현과 폐기안을 명확히 구분합니다.

## 아키텍처 변천사

```
[역설계 단계 (2024.09)]
Arduino UNO + Bluetooth 통신 + App Inventor(블록코딩) + MySQL(구상)
데이터 흐름: 아두이노 → 블루투스 통신 → 앱인벤터 → 데이터베이스
        │
        │  1차 회의(재설계 착수): ESP8266 채택, MySQL 유지
        ▼
[재설계 1차 (2024.10 초)]
ESP8266 + MySQL(구상) + 적외선 트래킹 센서
        │
        │  2차 회의: "아두이노에서 MySQL로 직접 진입 불가" 판단
        │  → 데이터베이스를 MySQL에서 Firebase로 교체
        ▼
[재설계 2차]
ESP8266 + Firebase
데이터 흐름: 아두이노 → 데이터베이스(Firebase) → 모니터링 프로그램
        │
        │  3차 회의: 광센서 각도 조정, 센서 2개 구성으로 회로 수정
        │  → 보드를 ESP8266에서 ESP32로 교체
        ▼
[최종 구현 (2024.12 완료)]
ESP32 + WiFi(내장) + Firebase Realtime Database
+ Android Studio 앱 (App Inventor 대체)
+ WPF(C#) 데스크톱 프로그램 (FireSharp로 Firebase 연동)
```

## 최종 구현에 포함된 것
- ESP32 보드, WiFi(내장 모듈), HX711 로드셀, TCRT5000 광센서(2개 구성), LCD(I2C)
- Firebase Realtime Database
- Android Studio 기반 모바일 앱 (Java)
- WPF(C#) 기반 데스크톱 모니터링 프로그램 (FireSharp)
- Rhino 8 기반 3D 프린팅 케이스

## 폐기된 설계 (최종 구현에 포함되지 않음)
| 폐기 항목 | 대체된 것 | 폐기 시점(근거) |
|---|---|---|
| Arduino UNO | ESP8266 → ESP32 | 재설계 착수 시점 |
| Bluetooth 통신 | WiFi(ESP32 내장) | 재설계 초기 |
| App Inventor(블록코딩) | Android Studio(Java) | 재설계 진행 중 |
| MySQL 직접연동 | Firebase Realtime Database | 2차 회의("아두이노에서 MySQL 직접 진입 불가") |
| ESP8266 | ESP32 | 3차 회의(회로 수정과 함께 교체) |

## 미구현/계획 수준 아이디어 (코드화하지 않음)
다음 항목은 `수정목록.txt`(팀 내부 메모)에 아이디어로만 존재하며, 회로도·코드·시연 근거가 전혀 없어 **[미구현/계획]**으로만 표시합니다.
- 팔 높게 들기 방지 알람 시스템
- 혈액 역류 방지 시스템

## App Inventor 처리 방침
초기 역설계 단계에서 실제로 사용된 사실은 확인되지만, `.aia` 프로젝트 파일 원본이 자료에 존재하지 않고 최종 시스템은 Android Studio로 완전히 대체되었습니다. 따라서 이번 복원 작업에서는:
- App Inventor용 파일을 새로 만들지 않았습니다.
- 최종 모바일 앱 코드(`mobile-app/`)에는 App Inventor 관련 산출물을 포함하지 않았습니다.
- 이 문서에만 전환 과정으로 기록합니다.

## 제외된 내용에 대한 안내
원본 최종보고서에는 3D 모델링 소프트웨어(Rhino 8)의 **비정상적인 설치 방법에 관한 설명**이 일부 포함되어 있었습니다. 해당 내용은 공개용 저장소 정책상 부적절하다고 판단하여 이 작업폴더의 어떤 문서에도 옮기지 않았습니다(구체적 방법·파일명·절차는 기록하지 않음).

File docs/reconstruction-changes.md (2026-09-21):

# Reconstruction Changes (3단계)

이 문서는 신규 코드와 과거 원본 코드를 절대 혼동하지 않도록, 3단계에서 이루어진 모든 변경/생성 작업을 6가지로 분리해 기록합니다.

---

## 1. 원본 그대로 복사
- `firmware/esp32_iv_monitor/esp32_iv_monitor.ino` — 2단계에서 이미 완료(변경 없음, SHA256 동일 유지)

## 2. 문서 원문 그대로 복원
- `mobile-app/recovered-source/com/example/a02/MainActivity.java`, `MainActivity01.java` — 2단계에서 이미 완료, **이번 3단계에서 한 글자도 수정하지 않았습니다.**

## 3. 신규 Android 재구성 (`mobile-app/reconstructed-app/`)
모두 **[신규 재구성]**이며 당시 원본이 아닙니다.

| 파일 | 근거 |
|---|---|
| `settings.gradle`, `build.gradle`, `gradle.properties`, `app/build.gradle` | 원본 Gradle 파일 없음. 이 PC의 기존 Android SDK(platform 34/35, build-tools 34.0.0/35.0.0)와 로컬 Gradle 캐시(AGP 8.6.0/8.7.2, Gradle 8.9)에 맞춰 새로 작성 |
| `app/src/main/AndroidManifest.xml` | 원본 없음. recovered-source의 실제 Activity 2개(MainActivity, MainActivity01)만 선언, INTERNET permission만 추가(Firebase 통신 근거) |
| `app/src/main/java/com/example/a02/MainActivity.java`, `MainActivity01.java` | recovered-source를 그대로 복사한 뒤, **컴파일 오류 1건만** 최소 수정(아래 "Android 원문 수정 내역" 참조) |
| `app/src/main/res/layout/activity_main.xml`, `activity_main01.xml` | 원본 XML 없음. 최종보고서 ver1.5.0 "코드 설명" 원문 텍스트(ConstraintLayout/CardView 속성값, 텍스트 문구, 색상 hex)를 근거로 재구성. recovered Java가 참조하는 View ID(`button2`, `textViewend1`, `textViewstart1`, `button05`)만 정확히 반영 |
| `app/src/main/res/values/colors.xml` | `#ECF1E6`, `#EAF1E1`은 문서 원문 hex 값 그대로. `green`/`green2`는 이름만 언급되고 실제 hex는 없어 **reconstructed approximation**으로 표시 |
| `app/src/main/res/values/strings.xml`, `themes.xml` | 신규 작성(Material3 미도입, AppCompat 최소 테마만 사용) |
| `app/src/main/res/drawable/border_shape.xml` | 원문 텍스트("네모난 빈 틀") 근거로 재구성, 색상/두께는 근사치 |
| `app/src/main/res/drawable/card_background.xml` | 아래 "빌드 호환 대체" 참조 |

### Android 원문 수정 내역 (recovered-source → reconstructed-app 사본, 이 사본에서만 적용)
| 파일 | 수정 내용 | 사유 |
|---|---|---|
| `MainActivity.java` | `import androidx.activity.EdgeToEdge;` 삭제 | 원문에서도 실제로 사용되지 않는 import였고, 빌드에 사용한 `androidx.activity:activity:1.7.0`에는 이 클래스가 없어 컴파일 에러(`cannot find symbol`) 발생. **명백한 compile error에 대한 최소 수정** |
| `MainActivity01.java` | 동일하게 `import androidx.activity.EdgeToEdge;` 삭제 | 위와 동일 사유 |

그 외 원문의 특이사항(중복 import, 미사용 필드 `textView03`, `onCancelled`에서 `textViewend1`을 잘못 갱신하는 부분)은 **빌드를 막지 않으므로 수정하지 않고 그대로 두었습니다.**

### 빌드 호환 대체 (라이브러리 → 표준 위젯)
최종보고서 원문은 메인화면에 `ConstraintLayout`+`CardView` 사용을 명시하고 있어 처음에는 `androidx.constraintlayout:constraintlayout:2.1.4`, `androidx.cardview:cardview:1.0.0`를 그대로 포함했습니다. 그러나 이 빌드 환경(Gradle 8.9 + AGP 8.6.0 + JDK 21)에서 두 라이브러리의 커스텀 XML 속성(`app:layout_constraintTop_toTopOf`, `app:cardCornerRadius` 등)이 `processDebugResources`(AAPT2 리소스 링크) 단계에서 **"attribute res-auto:... not found"** 오류로 전부 실패하는 것을 확인했습니다.

진단 과정(모두 재현됨):
1. 프로젝트 경로에 한글이 포함되어 발생하는 문제인지 의심 → ASCII 전용 임시 경로로 복사해 재현 → **동일하게 실패**(한글 경로 문제 아님)
2. Gradle 캐시가 오염된 것인지 의심 → `gradle clean --rerun-tasks`로 캐시 무효화 후 재시도 → **동일하게 실패**
3. ConstraintLayout/CardView가 실제로 `debugCompileClasspath`에 해석되는지 확인 → 정상 해석됨, `ExtractAarTransform`도 정상 수행됨(`--info` 로그로 확인)
4. CardView 없이 ConstraintLayout 속성만 단독으로 테스트 → **동일하게 실패**(두 라이브러리 각각의 문제가 아니라 공통적인 환경 이슈로 판단)
5. 표준 프레임워크 위젯(`LinearLayout`, `Button`, `TextView`)만으로 별도 레이아웃을 만들어 테스트 → **정상 링크 성공**

원인을 완전히 특정하지는 못했으나(이 환경의 AAPT2/AGP 조합에 한정된 문제로 추정), "단순하게 재현"이라는 3단계 원칙에 따라 **ConstraintLayout/CardView를 걷어내고 표준 LinearLayout + shape drawable(`card_background.xml`, 문서 원문의 `cardCornerRadius=20dp`, `cardBackgroundColor=#ECF1E6` 값을 그대로 반영)로 동일한 배치/색상을 재현**했습니다. `app/build.gradle`에서 두 의존성도 제거했습니다. 라이브러리를 임의로 "다른 라이브러리"로 바꾼 것이 아니라, 문서에 없는 라이브러리 자체를 걷어내고 프레임워크 기본 기능으로 대체한 것입니다.

## 4. 신규 WPF 재구현 (`desktop-app/reimplemented-wpf/`)
모두 **[신규 재구현]**이며 당시 원본이 아닙니다. `desktop-app/README.md`에 정리된 확인된 클래스명/메서드명/DataGrid 컬럼/Firebase 경로/5초 주기 갱신/환자정보 입력 흐름만 근거로 새로 작성했습니다.

| 파일 | 내용 |
|---|---|
| `IvMonitorDesktop.sln`, `IvMonitorDesktop.csproj` | 신규 작성. Target Framework는 "16. WPF Target Framework" 참조 |
| `App.xaml`, `App.xaml.cs` | 표준 WPF 진입점(최소) |
| `MainWindow.xaml`, `MainWindow.xaml.cs` | DataGrid 6컬럼(호실/이름/시작시간/종료시간/예상종료시간/진행도) + 확인된 메서드명(UpdateInfo, Info, Setting, OnTimeEvent, UpdateInfoForItem, LoadData, Read_Value, BtnName_Click, SetNowEnd) 전부 반영 |
| `Window2.xaml`, `Window2.xaml.cs` | 환자정보 입력창(이름/투여시간(분→TimeSpan)/투여용량/수액종류) + `btn1_Click` |
| `PatientRow.cs` | DataGrid 바인딩용 모델(원문에 클래스명 언급 없음, 신규 설계) |
| `FirebaseSettings.example.cs` | config example/template. 실제 AuthSecret/BasePath 없음 |

## 5. CAD 선별/파일명 변경
- 최종본으로 선정: `케이스 외형 출력 디자인.3dm`(2024-11-18) + `케이스 외형 출력 디자인.stl`(2024-11-19) → 이 둘은 파일명이 동일한 쌍이고 STL이 3dm 하루 뒤에 생성되어, 이 3dm이 실제로 STL로 출력(내보내기)된 버전이라는 근거가 명확합니다.
- `hardware/case-design/iv_monitor_case.3dm`, `iv_monitor_case.stl`로 이름만 일반화해 복사. **내용은 SHA256 해시로 원본과 100% 동일함을 확인**했습니다(자세한 근거는 21~24번 항목 참조).
- **복사하지 않은 CAD 후보와 사유**는 아래 "CAD 최종본 조사" 절 참조.

## 6. 보안을 위해 추가한 template/config 처리
- `desktop-app/reimplemented-wpf/IvMonitorDesktop/FirebaseSettings.example.cs` — 실제 값 없이 `YOUR_FIREBASE_AUTH_SECRET` / `YOUR_PROJECT_ID` 플레이스홀더만 포함. 파일명에 `.example`을 붙여 실제 설정 파일(`FirebaseSettings.cs`, 커밋 금지 대상)과 구분되도록 함.
- Android 쪽은 이미 2단계의 `.ino` 원본이 플레이스홀더 상태였고, 이번 3단계에서 별도 config 파일을 추가하지 않았습니다(원본 그대로 유지 원칙).
- `mobile-app/reconstructed-app/local.properties`는 이 PC의 로컬 Android SDK 경로만 담고 있으며(개인정보 아님), Android 프로젝트 관례상 항상 `.gitignore` 대상입니다 — 다음 단계 `.gitignore` 작성 시 반드시 포함되어야 합니다.

---

## CAD 최종본 조사 (21~24번 항목 상세)

### 파일별 조사 결과
| 파일 | 수정일 | 크기 | 판단 |
|---|---|---|---|
| 케이스모델 디자인.3dm | 2024-11-09 | 85.8 KB | 초기 컨셉 스케치로 판단(가장 이른 날짜, 가장 작은 크기) |
| 4조_외형도안.3dm / .3dmbak | 2024-11-12 | 985.3 KB | 4차 회의(2024-11-12, 케이스 디자인 논의)와 날짜 일치. 전체 부품 통합 도면으로 추정(용량이 가장 큼) |
| **케이스 외형 출력 디자인.3dm** | 2024-11-18 | 262.2 KB | **STL과 페어링된 유일한 3dm** → 최종본으로 채택 |
| **케이스 외형 출력 디자인.stl** | 2024-11-19 | 274.1 KB | **폴더 내 유일한 STL 파일** → 실제 출력에 사용된 파일로 채택 |
| 케이스 외형 출력 디자인1.3dm / .3dmbak | 2024-11-25 / 26 | 231.8 / 231.1 KB | 6차 회의(2024-11-26, "수액 케이스 조립") 직전 최신 수정본이지만, **대응하는 STL이 없어 이 버전이 실제로 출력되었다는 근거가 없음** |
| *.3dmbak (전체) | — | — | Rhino 자동 백업 파일 — 원칙대로 전부 제외 |

### 판단 및 한계
"케이스 외형 출력 디자인1.3dm"이 날짜상으로는 가장 최신이지만, **STL 출력물과 직접 대응되는 파일이 아니므로** 이번 3단계에서는 `hardware/case-design/`에 복사하지 않았습니다. 이 파일이 실제 최종 조립에 쓰인 근본 디자인인지, 아니면 출력 이후의 미세 조정(출력과 무관한 내부 배치 변경 등)인지는 **문서만으로 확정할 수 없어 [판단 불가]**로 남깁니다. 필요 시 다음 단계에서 이 파일도 참고용으로 별도 포함할 수 있습니다(사용자 확인 필요).

### CAD 파일명 일반화 및 해시 검증
```
원본: 케이스 외형 출력 디자인.3dm
사본: hardware/case-design/iv_monitor_case.3dm
SHA256(원본) = 6ee5b9e4aca50f48c0c6bf2c79445ff80fb311299e47739b4f525db3524f2d4b
SHA256(사본) = 6ee5b9e4aca50f48c0c6bf2c79445ff80fb311299e47739b4f525db3524f2d4b  (동일)

원본: 케이스 외형 출력 디자인.stl
사본: hardware/case-design/iv_monitor_case.stl
SHA256(원본) = 3599b7c6182944d6a2c27390522f9529293366e06db966672c309b8dbddf050c
SHA256(사본) = 3599b7c6182944d6a2c27390522f9529293366e06db966672c309b8dbddf050c  (동일)
```
파일명만 변경, 내용은 100% 동일합니다.

### CAD 내부 metadata 검사
- STL 헤더(첫 80바이트): `"Rhinoceros Binary STL ( Nov 12 2024 )"` — 이는 Rhino 소프트웨어 자체의 빌드/버전 문자열로 보이며, 파일의 실제 내보내기 날짜(2024-11-19, 파일시스템 mtime)와는 무관합니다. 개인정보는 아닙니다.
- 3dm 파일들에 대해 팀원 실명 패턴, 이메일 패턴, `C:\Users\...` 절대경로 패턴을 바이너리 레벨로 스캔한 결과 **검출되지 않았습니다.**
- 다만 Rhino의 OpenNURBS 바이너리 포맷 내부에는 "문서 속성(작성자, 회사명 등)" 필드가 별도로 존재할 수 있으며, 전용 SDK/Rhino 프로그램 없이는 이 필드를 완전히 파싱해 확인할 수 없습니다 → **[확인 불가]**로 정직하게 남깁니다. 공개 전 Rhino에서 직접 열어 "문서 속성"을 확인/삭제할 것을 권장합니다.

---

## WPF Target Framework 선택 근거 (16번 항목)
- 문서(최종보고서, WPF 담당 팀원 개인보고서)에는 정확한 .NET Target Framework 버전이 전혀 언급되어 있지 않습니다 → 원본 근거 없음.
- 이 PC 확인 결과: `dotnet --info` 기준 **.NET SDK는 설치되어 있지 않고**, .NET 7 런타임(`Microsoft.WindowsDesktop.App 7.0.0`, `Microsoft.NETCore.App 7.0.0`)만 설치되어 있습니다.
- SDK가 없어 실제 빌드는 애초에 불가능하지만, "설치되면 가장 호환 가능성이 높은" 선택으로 **net7.0-windows**를 지정했습니다. 이는 **[신규 재구현용 기술 선택]**이며 과거 원본 환경이 아닙니다.

## FireSharp 처리 결과 (17번 항목)
- `IvMonitorDesktop.csproj`에 `PackageReference Include="FireSharp" Version="2.0.4"`를 그대로 포함했습니다(다른 라이브러리로 교체하지 않음).
- **알려진 위험**: FireSharp은 2016년경 마지막으로 배포되었고 .NET Framework 4.5를 대상으로 하는 것으로 알려져 있어, `net7.0-windows`(SDK 스타일 프로젝트)와의 실제 호환성은 **검증되지 않았습니다.**
- 이 PC에 .NET SDK가 없어 `dotnet restore`/`dotnet build`를 실제로 실행할 수 없었고, 따라서 "빌드된다" 또는 "빌드되지 않는다"를 확정할 수 없습니다 → **[확인 필요/미검증]**으로 보고합니다. 임의로 다른 Firebase 클라이언트 라이브러리로 바꾸지 않았습니다.

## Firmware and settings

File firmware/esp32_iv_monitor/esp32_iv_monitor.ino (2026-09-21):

#include <Arduino.h>        // 아두이노 라이브러리
#include <WiFi.h>           // ESP32 와이파이 라이브러리
#include <FirebaseESP32.h>  // Firebase 연동 라이브러리 (ESP32 용)
#include <addons/TokenHelper.h> // Firebase 인증 토큰 처리 관련 유틸리티
#include <addons/RTDBHelper.h> // Firebase Realtime Database 헬퍼 함수 제공
#include <HX711.h>          // 로드셀 라이브러리
#include <LiquidCrystal_PCF8574.h> // lcd 라이브러리
#include <Wire.h>           // I2C 통신 라이브러리
#include <time.h>           // 시간 관련 라이브러리

LiquidCrystal_PCF8574 lcd(0x27);  // LCD 주소 설정 (주소는 0x27 또는 0x3F일 수 있음)

// 버튼
#define Rstart_PIN 18
#define Start_PIN 5

// 무게 센서 핀 설정
#define DT_PIN 12          // HX711의 DT 핀 (ESP32의 GPIO 12)
#define SCK_PIN 13         // HX711의 SCK 핀 (ESP32의 GPIO 13)
HX711 scale;               // HX711 객체 생성

// 광센서 핀 설정
#define TCR_PIN 4          // ESP32의 GPIO 4로 설정
volatile bool dropletDetected = false; // 물방울 감지 상태를 저장하는 변수
int count = 0;

void IRAM_ATTR handleDroplet() {
  dropletDetected = true; // 인터럽트 발생 시 감지 상태를 true로 설정
}

// WiFi 설정
const char* ssid = "와이파이 이름 작성";           // Wi-Fi 이름
const char* password = "와이파이 비밀번호 작성";  // Wi-Fi 비밀번호

// NTP 서버 및 시간 설정
const char* ntpServer = "pool.ntp.org";
const long gmtOffset_sec = 9 * 3600;
const int daylightOffset_sec = 0;

// Firebase 설정
#define API_KEY "파이어베이스 API 키 작성"           
#define DATABASE_URL "파이어 베이스 URL 주소 작성"   
#define USER_EMAIL "사용자 이메일"                            
#define USER_PASSWORD "비밀번호 작성"

// Firebase 객체 선언
FirebaseConfig firebaseConfig;  // Firebase 설정 정보를 담는 객체
FirebaseAuth firebaseAuth;      // Firebase 인증 정보를 담는 객체
FirebaseData firebaseData;      // Firebase 데이터 전송/수신을 위한 객체

// 변수 처리
bool startpart = true;
bool firstpart = false;
bool secondpart = false;
bool thirdpart = false;

float setweight = 100.0; // 수액통, 센서 무게
float pweight = 0;       // 10초 전의 무게
float aweigh = 0;        // 10초 후의 무게
float weight = 0;        // 현재 무게
float savespeed = 0;
float startweight = 0;

int savetime = 0;        // 남은시간 저장 (초)
int savecount = 0;      // 물방울 횟수

// 저장된 시작 시간
int startHour = 0, startMinute = 0, startSecond = 0;

// 종료시간
int endHour = 0, endMinute = 0, endSecond = 0;

// 시간 동기화 함수
void synchronizeTime() {
  configTime(gmtOffset_sec, daylightOffset_sec, ntpServer);
  struct tm timeinfo;
  Serial.println("시간 동기화 중...");
  for (int i = 0; i < 10; i++) { // 최대 10초 동안 시도
    if (getLocalTime(&timeinfo)) {
      Serial.println("시간 동기화 성공!");
      return;
    }
    delay(1000); // 1초 대기
  }
  Serial.println("시간 동기화 실패!");
}

void saveCurrentTime() {
  struct tm timeinfo;
  if (!getLocalTime(&timeinfo)) {
    Serial.println("시간 동기화 실패");
    return;
  }
  startHour = timeinfo.tm_hour;
  startMinute = timeinfo.tm_min;
  startSecond = timeinfo.tm_sec;
  Serial.printf("저장된 시작 시간: %02d:%02d:%02d\n", startHour, startMinute, startSecond);
}

String getTime(){
  char buffer[9];
  sprintf(buffer, "%02d:%02d:%02d", startHour, startMinute, startSecond);
  String currentTime = String(buffer); // 포맷된 시간 문자열로 변환
  return currentTime; // 현재 시간 반환
}

void calculateEndTime(int remainingSeconds) { //종료시간 예측
  struct tm timeinfo;
  if (!getLocalTime(&timeinfo)) {
    Serial.println("시간 동기화 실패");
    return;
  }

  time_t now = mktime(&timeinfo);
  time_t end = now + remainingSeconds;
  struct tm* endTime = localtime(&end);

  endHour = endTime->tm_hour;
  endMinute = endTime->tm_min;
  endSecond = endTime->tm_sec;

  Serial.printf("종료 시간: %02d:%02d:%02d\n", endHour, endMinute, endSecond);

  // LCD에 종료 시간 표시
  lcd.setCursor(0, 0);
  lcd.print("endT ");
  lcd.printf("%02d:%02d:%02d", endHour, endMinute, endSecond);
}

String getEndTime(){ // 종료시간 반환
  char buffer[9];
  sprintf(buffer, "%02d:%02d:%02d", endHour, endMinute, endSecond);
  String currentTime = String(buffer); // 포맷된 시간 문자열로 변환
  return currentTime; // 현재 시간 반환
}

void setup() {
  lcd.begin(16, 2);
  lcd.setBacklight(255); // LCD 백라이트 켜기
  lcd.setCursor(0, 0);
  lcd.print("Initializing...");

  pinMode(Start_PIN, INPUT_PULLUP);
  pinMode(Rstart_PIN, INPUT_PULLUP);

  Serial.begin(115200); // 시리얼 통신 초기화
  delay(3000);
  Serial.println("시작");

  scale.begin(DT_PIN, SCK_PIN); // 로드셀 초기화
  scale.set_scale(309);         // 보정값 설정
  scale.tare();                 // 현재 무게를 0으로 설정

  pinMode(TCR_PIN, INPUT);

  Serial.print("와이파이 연결중: ");
  WiFi.begin(ssid, password);
  while (WiFi.status() != WL_CONNECTED) {
    delay(500);
    Serial.print(".");
  }
  Serial.println("\n와이파이 연결 성공!");

  synchronizeTime(); // NTP 시간 동기화 호출

  firebaseConfig.api_key = API_KEY;
  firebaseConfig.database_url = DATABASE_URL;
  firebaseAuth.user.email = USER_EMAIL;
  firebaseAuth.user.password = USER_PASSWORD;

  Firebase.begin(&firebaseConfig, &firebaseAuth);

  if (!Firebase.ready()) {
    Serial.println("Firebase 초기화 실패!");
  } else {
    Serial.println("Firebase 초기화 성공!");
  }

  attachInterrupt(digitalPinToInterrupt(TCR_PIN), handleDroplet, FALLING);

  lcd.clear();
  lcd.setCursor(0, 0);
  lcd.print("Ready, done");
  lcd.setCursor(0, 1);
  lcd.print("Press Btn!");

  Serial.println("버튼을 눌러주세요");
}

void loop() {
  if (digitalRead(Rstart_PIN) == LOW) {
    Serial.println("버튼이 눌렸습니다. 보드를 재시작합니다...");
    delay(1000);
    ESP.restart();
  }

  if (startpart == true && digitalRead(Start_PIN) == LOW) {

    lcd.clear();
    lcd.setCursor(0, 0);
    lcd.print("Wait");
    lcd.setCursor(0, 1);
    lcd.print("Measuring...");

    weight = scale.get_units(10);
    firstpart = true;
    startpart = false; 
    startweight = weight - setweight;

    saveCurrentTime();

    if (Firebase.setFloat(firebaseData, "/802/StartWeight", weight)) {
      Serial.println("무게 데이터 전송 성공: " + String(weight) + "g");
    } else {
      Serial.print("무게 데이터 전송 실패: ");
      Serial.println(firebaseData.errorReason());
    }
    delay(2000);

    if (Firebase.setString(firebaseData, "/802/StartTime", getTime())) {
        Serial.println("측정 시간 데이터 전송 성공: " + getTime());
    } else {
        Serial.print("측정 시간 데이터 전송 실패: ");
        Serial.println(firebaseData.errorReason());
    }
    delay(2000);
  }

  while (firstpart) {
    if (digitalRead(Rstart_PIN) == LOW) {
        Serial.println("보드를 재시작합니다...");
        delay(1000);
        ESP.restart();
    }

    Serial.println("정상적 첫 파트 변경 완료");

    // 10초 전 무게 측정
    float startWeight = scale.get_units(10) - setweight;
    Serial.println("10초 전 무게: " + String(startWeight));

    int dropCount = 0; // 물방울 횟수를 세는 변수
    bool lastDetection = false; // 이전 물방울 감지 상태 변수

    unsigned long startTime = millis();
    while (millis() - startTime < 10000) {
        bool currentDetection = digitalRead(TCR_PIN) == HIGH;

        if (currentDetection && !lastDetection) { // 새로운 물방울 감지가 발생한 경우
            dropCount++;
            
            // 물방울이 완전히 떨어질 때까지 대기
            while (digitalRead(TCR_PIN) == HIGH) {
                // 센서가 LOW 상태로 돌아올 때까지 대기
            }
        }
        
        lastDetection = currentDetection; // 현재 감지 상태를 기록
    }

    // 10초 후 무게 측정
    float endWeight = scale.get_units(10) - setweight;
    Serial.println("10초 후 무게: " + String(endWeight));

    // 물방울 횟수 출력
    Serial.println("10초 동안 떨어진 물방울 수: " + String(dropCount));

    // 무게 변화량 계산
    float weightChange = startWeight - endWeight; // 무게 변화량

    // 평균 물방울당 무게 계산
    float weightPerDrop = (dropCount > 0) ? weightChange / dropCount : 0;
    Serial.println("평균 물방울당 무게: " + String(weightPerDrop) + " g");

    // 속도 계산 (g/s 단위로 계산)
    float speed = weightChange / 10; // 속도 (g/s)
    Serial.println("속도: " + String(speed) + " g/s");

    // 남은 시간 계산 (초 단위)
    float remainingTime = (speed != 0) ? endWeight / speed : -1;
    Serial.println("남은 시간: " + String(remainingTime) + " 초");
    savetime = remainingTime;

    // 음수 값 처리
    if (weightChange < 0) {
        Serial.println("이상한 움직임 감지 다시 측정");
        delay(1000); // 잠시 대기 후 다시 측정
        continue; // 루프 시작으로 되돌아감
    }
    lcd.clear();
    calculateEndTime(savetime);


    if (Firebase.setString(firebaseData, "/802/EndTime", getEndTime())) {  
        Serial.println("종료 시간 데이터 전송 성공: " + getEndTime());
    } else {
        Serial.print("종료 시간 데이터 전송 실패: ");
        Serial.println(firebaseData.errorReason());
    }
    delay(2000);

    if (Firebase.setFloat(firebaseData, "/802/speed", speed)) {
        Serial.println("속도 데이터 전송 성공: " + String(speed) + " g/s");
    } else {
        Serial.print("속도 데이터 전송 실패: ");
        Serial.println(firebaseData.errorReason());
    }
    delay(2000);
    
    savecount = dropCount;
    dropCount = 0;

    firstpart = false;
    secondpart = true;
  
    float proWeight = scale.get_units(10) - setweight;
    int progress = 100 - ((proWeight /startweight)*100);
  
    lcd.setCursor(0, 1);
    lcd.print("progress:");
    lcd.print(progress);
    lcd.print("%");

    
  }


  while (secondpart) {
    if (digitalRead(Rstart_PIN) == LOW) {
        Serial.println("보드를 재시작합니다...");
        delay(1000);
        ESP.restart();
    }

    // 10초 전 무게 측정
    float startWeight = scale.get_units(10) - setweight;
    Serial.println("10초 전 무게: " + String(startWeight));

    int dropCount = 0; // 물방울 횟수를 세는 변수
    bool lastDetection = false; // 이전 물방울 감지 상태 변수

    unsigned long startTime = millis();
    while (millis() - startTime < 10000) {
        bool currentDetection = digitalRead(TCR_PIN) == HIGH;

        if (currentDetection && !lastDetection) { // 새로운 물방울 감지가 발생한 경우
            dropCount++;
            
            // 물방울이 완전히 떨어질 때까지 대기
            while (digitalRead(TCR_PIN) == HIGH) {
                // 센서가 LOW 상태로 돌아올 때까지 대기
            }
        }
        
        lastDetection = currentDetection; // 현재 감지 상태를 기록
    }

    // 10초 후 무게 측정
    float endWeight = scale.get_units(10) - setweight;
    Serial.println("10초 후 무게: " + String(endWeight));

    // 물방울 횟수 출력
    Serial.println("10초 동안 떨어진 물방울 수: " + String(dropCount));

    // 무게 변화량 계산
    float weightChange = startWeight - endWeight; // 무게 변화량

    // 음수 값 처리
    if (weightChange < 0) {
        Serial.println("이상한 움직임 감지 다시 측정");
        delay(1000); // 잠시 대기 후 다시 측정
        continue; // 루프 시작으로 되돌아감
    }

    // 평균 물방울당 무게 계산
    float weightPerDrop = (dropCount > 0) ? weightChange / dropCount : 0;
    Serial.println("평균 물방울당 무게: " + String(weightPerDrop) + " g");

    // 속도 계산 (g/s 단위로 계산)
    float speed = weightChange / 10; // 속도 (g/s)
    Serial.println("속도: " + String(speed) + " g/s");

    // 남은 시간 계산 (초 단위)
    float remainingTime = (speed != 0) ? endWeight / speed : -1;
    Serial.println("남은 시간: " + String(remainingTime) + " 초");
    
    int pcount = savecount + 1;
    int mcount = savecount - 1;

    if(dropCount > pcount || dropCount < mcount ) //물방울 떨어지는 주기로 확인
    {
      savecount = dropCount;
      savetime = remainingTime;
      calculateEndTime(savetime);
      if (Firebase.setString(firebaseData, "/802/EndTime", getEndTime())) {
      Serial.println("종료 시간 데이터 전송 성공: " + getEndTime());
    } else {
      Serial.print("종료 시간 데이터 전송 실패: ");
      Serial.println(firebaseData.errorReason());
    }
    delay(2000);

    if (Firebase.setFloat(firebaseData, "/802/speed", speed)) {
      Serial.println("속도 데이터 전송 성공: " + String(speed) + " g/s");
    } else {
      Serial.print("속도 데이터 전송 실패: ");
      Serial.println(firebaseData.errorReason());
    }
    delay(2000);
    }
    // dropCount 초기화
    dropCount = 0;
    float proWeight = scale.get_units(10) - setweight;
    int progress = 100 - ((proWeight /startweight)*100);
    lcd.setCursor(0, 1);
    lcd.print("progress:");
    lcd.print(progress);
    lcd.print("%");
    Serial.println("진행도 :"+ (String)progress);
  }
}

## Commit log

2026-09-21 Initial commit: add Smart IV monitoring project archive
    [iv_monitor_case.3dm, iv_monitor_case.stl]
2026-09-21 Docs: clarify WPF reconstruction target framework
